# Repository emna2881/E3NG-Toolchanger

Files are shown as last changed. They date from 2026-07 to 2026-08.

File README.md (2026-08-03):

# E3NG-Toolchanger
A hotend-swapping toolchanger system modified for the E3NG (Ender-3 NG) 3D printer.

Render

> [!IMPORTANT]
> **Note: This project is currently in Beta. Community testing and feedback are greatly needed.**
> 
> **Some features(BOM, printer.cfg, marcos...) will be updated in a future release.**
## Credits
This project is based on E3NG by RH3D : https://github.com/RH3D/E3NG

Also, I designed mount for Metal Bed of Nudge probe for tool offset calibration. Thanks to zruncho3d for developing Nudge : https://github.com/zruncho3d/nudge

(+) The extruder design for this toolchanger was inspired by Irbis3D's MedusaHC (https://github.com/Irbis3D/MedusaHC). His DuEnder project and its accompanying hotend changer system, MedusaHC, are incredibly sophisticated and highly refined, and they were immensely helpful to me while designing the toolchanger system for the E3NG.

I would like to express my deepest gratitude to Irbis3D for his continuous efforts in advancing the Ender-3. Additionally, I sincerely apologize for the delay in adding this credit.

## Key Features
asdf

* Hotend-Swapping Mechanism: Swaps hotends while utilizing a single extruder drive gear set and a single pair of part cooling fans, significantly reducing toolhead weight and cost.
* Servo-Driven Cam Arm: Features a servo motor with a cam mechanism that disengages the extruder idler arm to clear the filament path for tool changes.
* Multi-Tool Capacity: Supports up to 6 tools (5 tools recommended for optimal clearance)

## Print Settings and Recommendations

To ensure mechanical strength and thermal resistance, please follow these guidelines when printing the parts:

### Material Selection
* Recommended: ABS or ASA (Best for enclosure heat resistance and structural integrity).
* Acceptable: PETG can be used if you are operating the printer without an enclosure.
* DO NOT USE PLA: PLA is strongly discouraged, especially for the hotend, toolhead, and carriage parts, due to heat deflection issues.

### Print Specifications
* Walls and Infill: Follow the official E3NG recommended print guidelines (e.g., 4 perimeters, 5 top/bottom layers, 30% infill)
* Supports: Most STL files are designed to be printed supportless. However, a few specific components require custom support setups (Detailed support guide will be added in a future update).

## License
This project is licensed under the terms of the [Creative Commons Attribution-NonCommercial-ShareAlike 4.0 International License](https://creativecommons.org/licenses/by-nc-sa/4.0/)


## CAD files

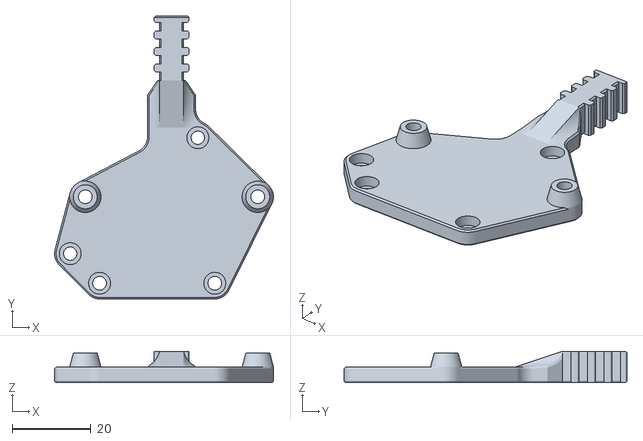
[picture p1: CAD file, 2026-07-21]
STLs/Accessories/E3NG_ToolChanger_ebb36_mount.stl
55.7 x 71.9 x 8.00

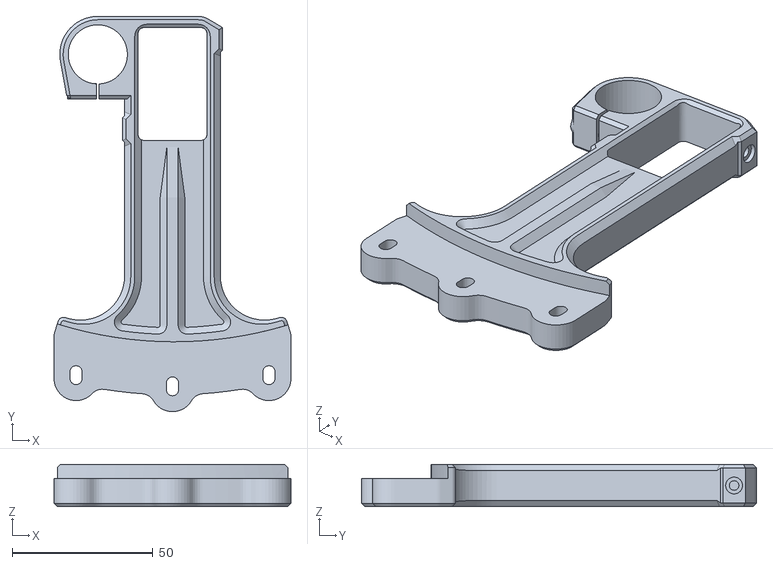
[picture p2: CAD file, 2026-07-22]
STLs/Bedcarriage/E3NG_ToolChanger_bed_arm_rear_flexi_tripple.stl
84.1 x 140.3 x 15.0

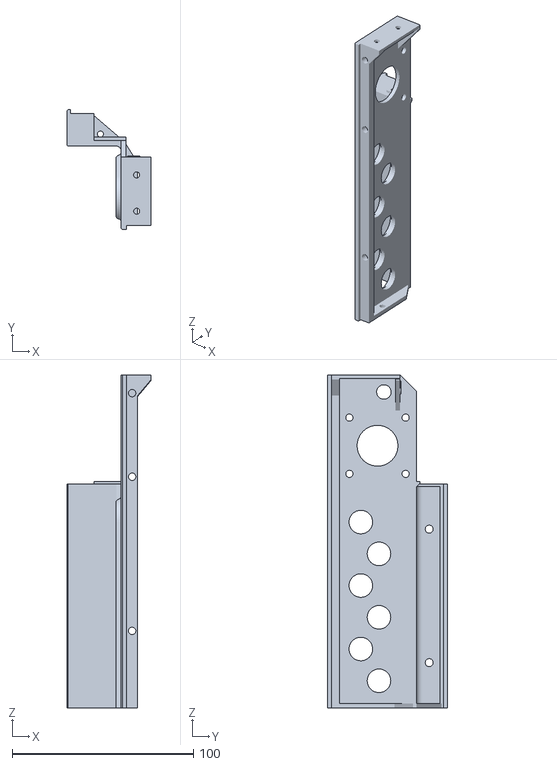
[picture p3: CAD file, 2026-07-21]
STLs/Electronics/E3NG_ToolChanger_electronics_top_A.stl
46.5 x 66.0 x 183.6

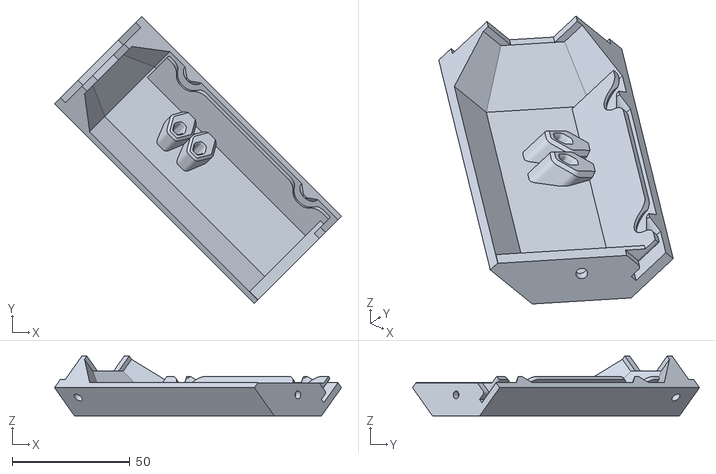
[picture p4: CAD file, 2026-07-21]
STLs/Enclosure/E3NG_ToolChanger_enclosure_lid_corner_left_2holes.stl
121.9 x 121.9 x 25.5

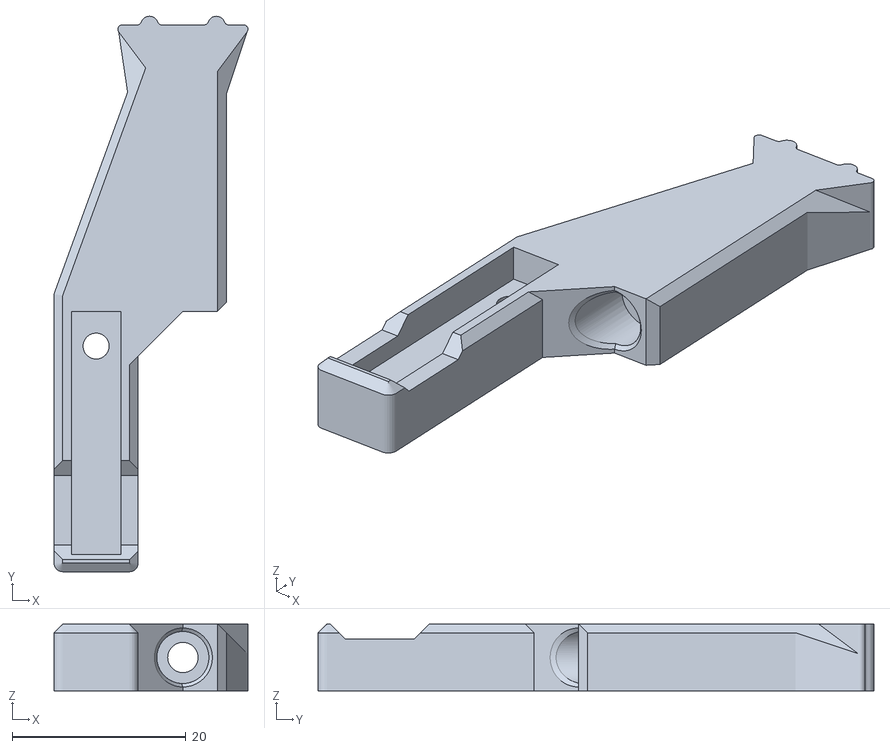
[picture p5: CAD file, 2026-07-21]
STLs/Experimental/E3NG_ToolChanger_nozzlewiper_wiper.stl
22.3 x 64.0 x 7.70

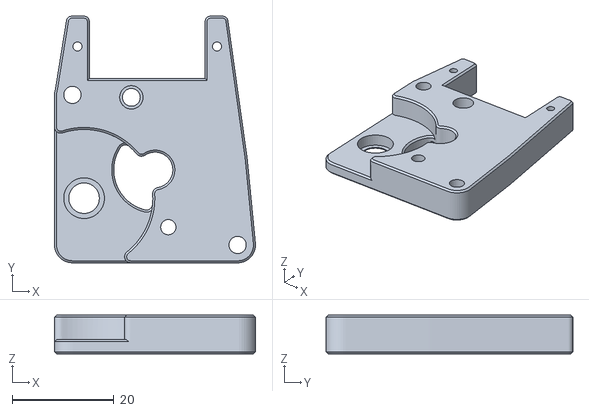
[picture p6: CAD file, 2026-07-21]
STLs/Extruder/E3NG_ToolChanger_extruder_base_with_pin.stl
39.5 x 48.5 x 7.60

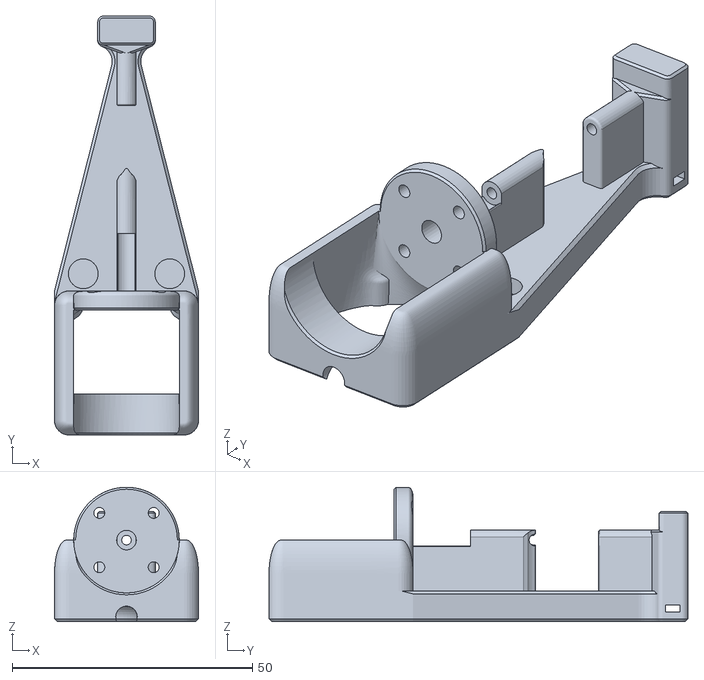
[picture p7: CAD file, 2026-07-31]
STLs/Tool/E3NG_ToolChanger_tool_A.stl
30.0 x 87.3 x 28.0

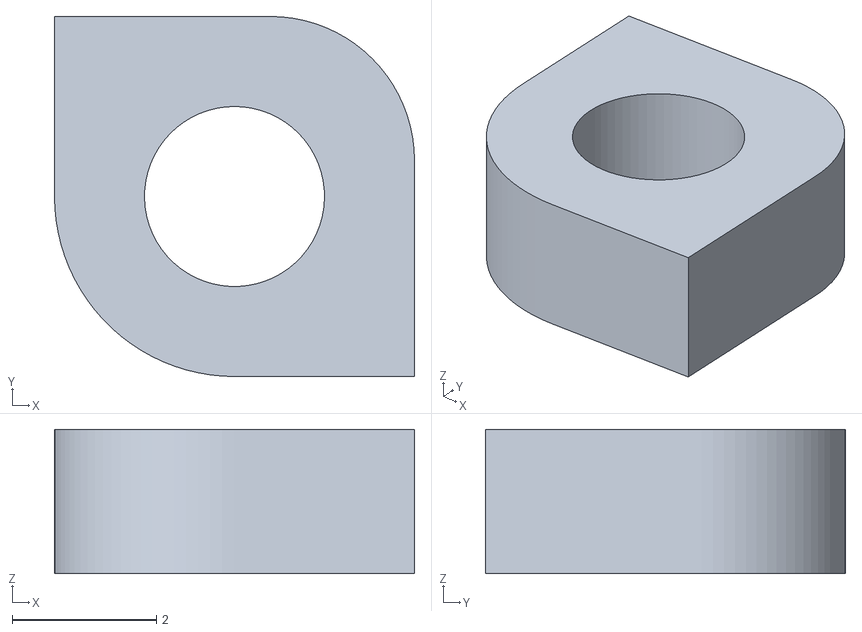
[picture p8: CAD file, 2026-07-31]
STLs/Toolhead/E3NG_ToolChanger_Fanduct_fan_spacer_2mm.stl
5.00 x 5.00 x 2.00

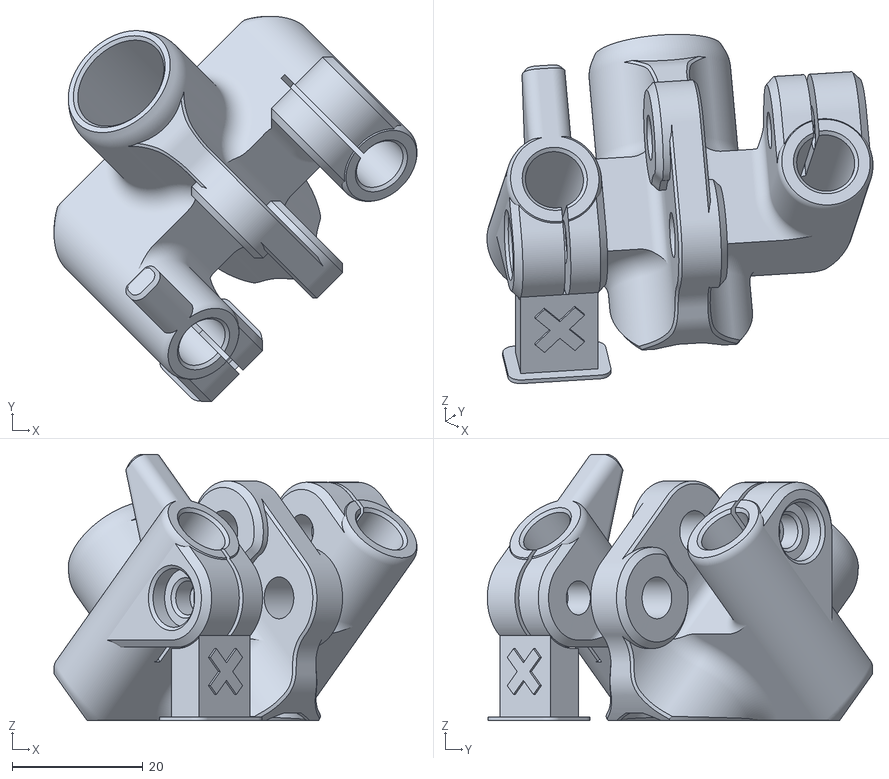
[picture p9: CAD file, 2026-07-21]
STLs/YGantry/E3NG_ToolChanger_y_gantry_v1.2_left.stl
55.5 x 59.0 x 40.8

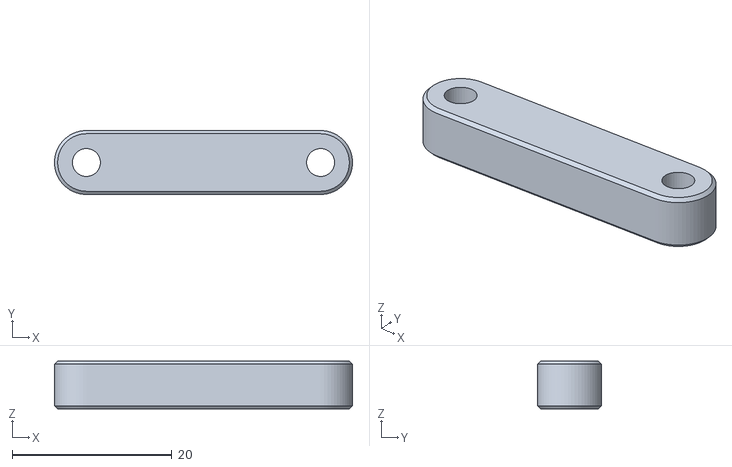
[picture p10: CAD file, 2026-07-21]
STLs/Accessories/E3NG_ToolChanger_ebbmount_spacer_6mm.stl
37.3 x 8.00 x 6.00

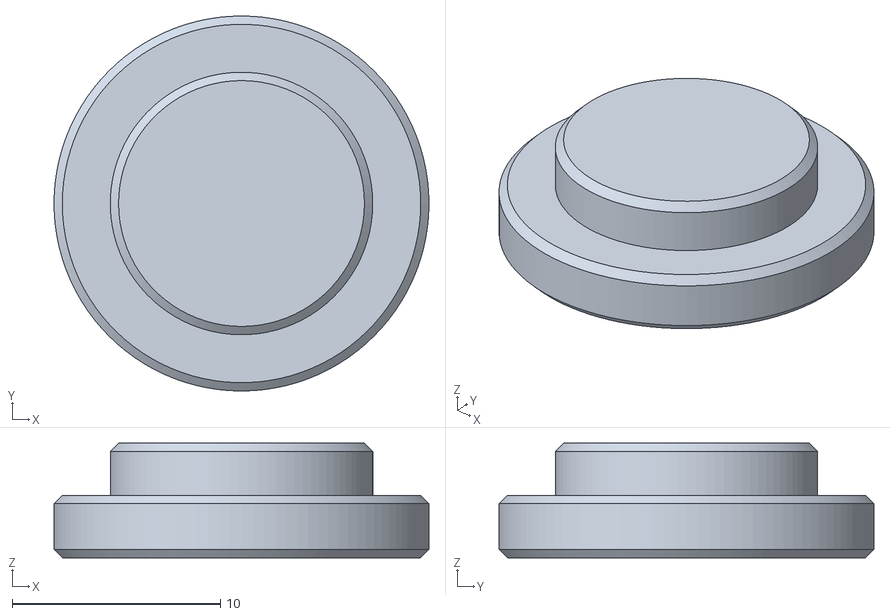
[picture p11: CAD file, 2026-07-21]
STLs/Electronics/E3NG_ToolChanger_electronics_top_A_hole_cover.stl
18.0 x 18.0 x 5.50

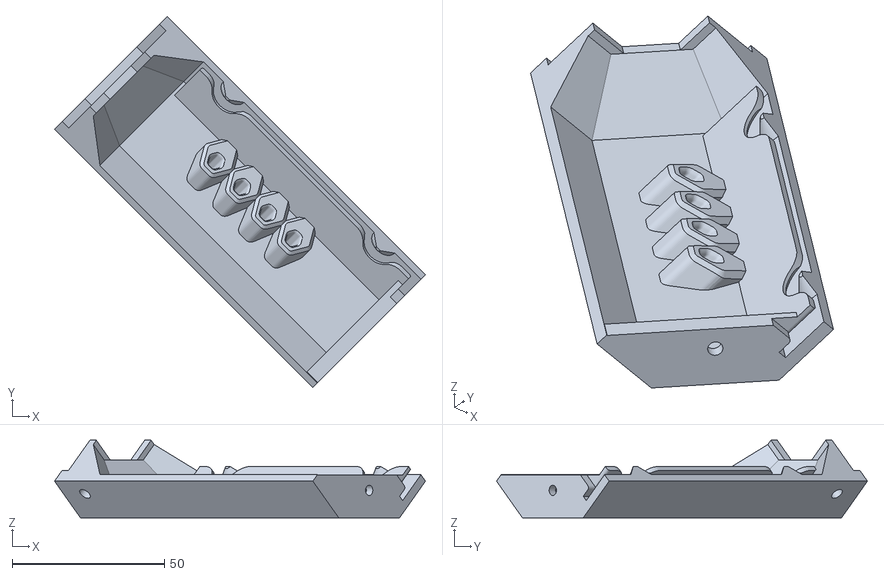
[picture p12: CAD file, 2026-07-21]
STLs/Enclosure/E3NG_ToolChanger_enclosure_lid_corner_left_4holes.stl
121.9 x 121.9 x 25.5

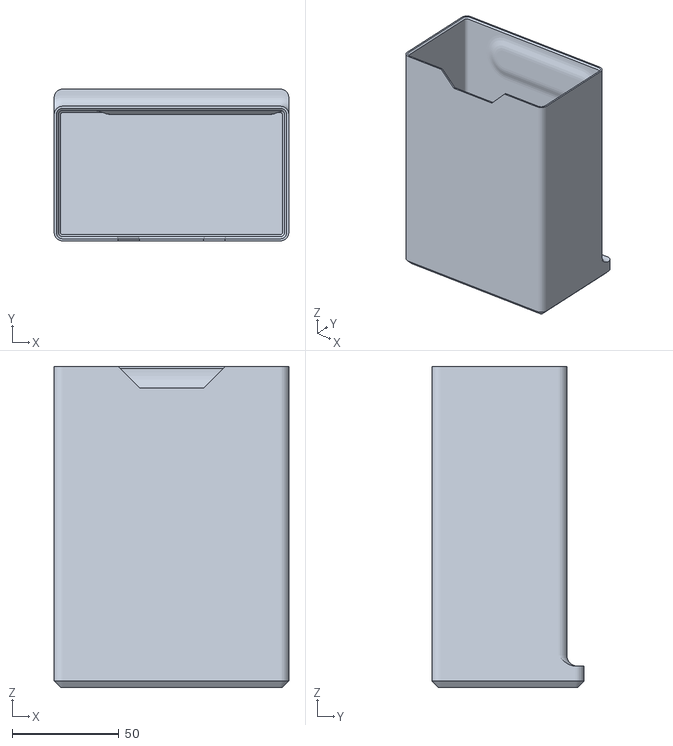
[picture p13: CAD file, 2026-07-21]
STLs/Experimental/E3NG_ToolChanger_nozzlewiper_bucket.stl
109.7 x 71.0 x 150.0

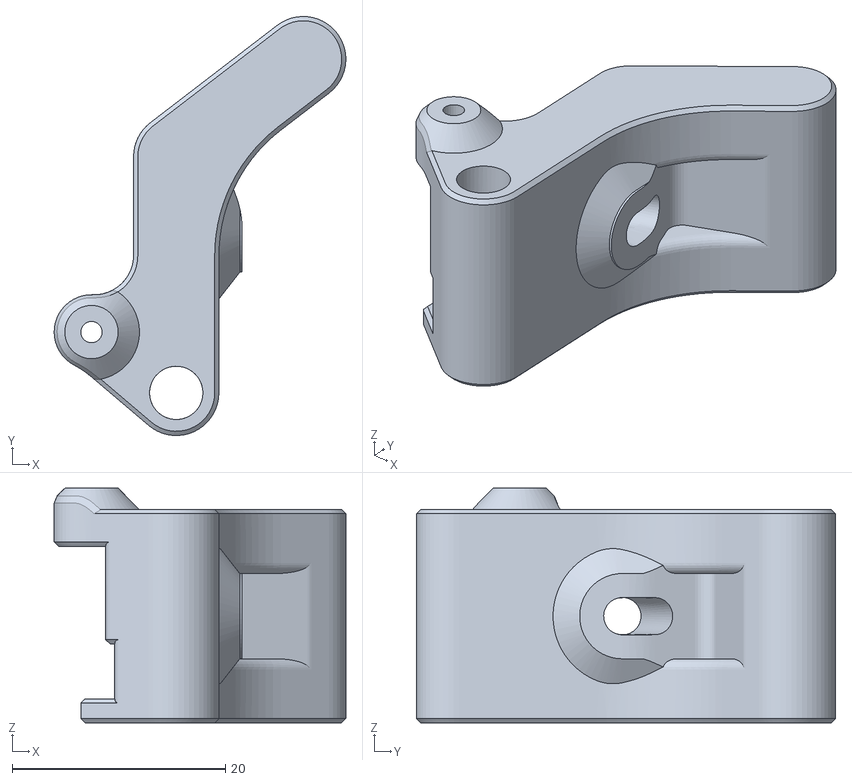
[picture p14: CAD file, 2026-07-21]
STLs/Extruder/E3NG_ToolChanger_extruder_arm_with_sleeve.stl
27.3 x 39.3 x 22.0

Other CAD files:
STLs/Tool/E3NG_ToolChanger_dock_B.stl
STLs/Toolhead/E3NG_ToolChanger_Toolhead_base.stl
STLs/YGantry/E3NG_ToolChanger_y_gantry_beta_B.stl
STLs/Accessories/E3NG_ToolChanger_ebbmount_spacer_3.5mm.stl
CAD/E3NG_Toolchanger_Profile_Bracket.f3d
STLs/Accessories/E3NG_ToolChanger_ebb42_mount.stl
STLs/Enclosure/E3NG_ToolChanger_enclosure_lid_corner_right_2holes.stl
STLs/Enclosure/E3NG_ToolChanger_enclosure_lid_corner_right_4holes.stl
STLs/Experimental/E3NG_ToolChanger_nozzlewiper_base.stl
STLs/Experimental/E3NG_ToolChanger_nudge_base_for_metal_bed.stl
STLs/Experimental/E3NG_ToolChanger_tool_park_left.stl
STLs/Experimental/E3NG_ToolChanger_tool_park_right.stl
STLs/Extruder/E3NG_ToolChanger_extruder_arm.stl
STLs/Extruder/E3NG_ToolChanger_extruder_base.stl
STLs/Extruder/E3NG_ToolChanger_extruder_core.stl
STLs/Extruder/E3NG_ToolChanger_extruder_core_with_pin.stl
STLs/Tool/E3NG_ToolChanger_dock_A.stl
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

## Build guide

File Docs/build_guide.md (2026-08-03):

# E3NG Toolchanger Official Documentation & BOM Guide

> *Disclaimer: This document was created with the assistance of AI translation. Please note that there may be awkward phrasing or grammatical errors, and we ask for your understanding.*

## General Build Guidelines
- **Bolt Substitution:** All 14mm bolts listed in the guide can be replaced with 15mm bolts.
- **Magnet Insertion:** When inserting magnets, using CA glue (superglue) is recommended to ensure they are firmly and permanently secured.

---

## Detailed Component Guide & BOM
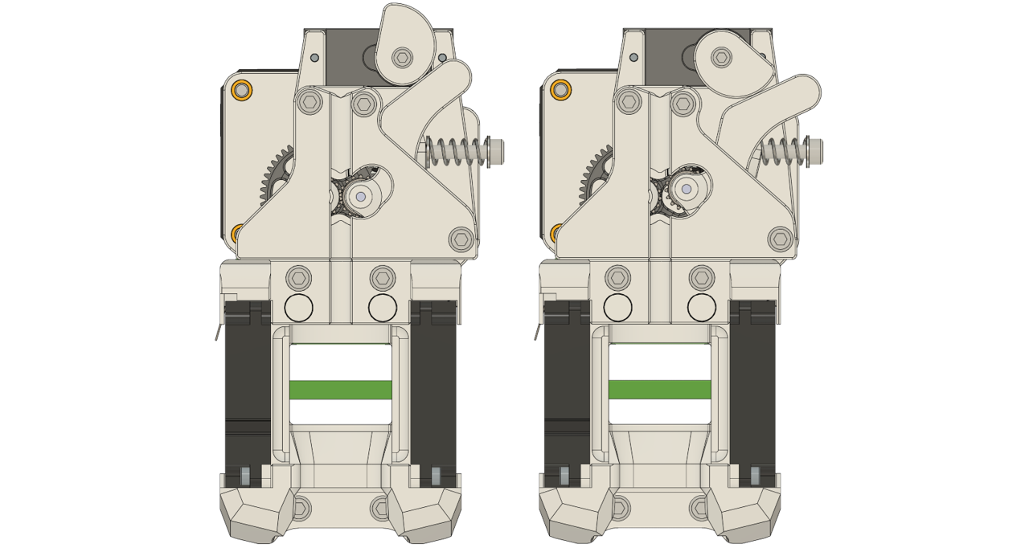
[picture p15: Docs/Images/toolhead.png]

The toolhead structure is simple and intuitive. A cam attached to the servo motor rotates to open the extruder gears. The tool and toolhead are securely held together by two pairs of neodymium magnets.

### 1. Extruder
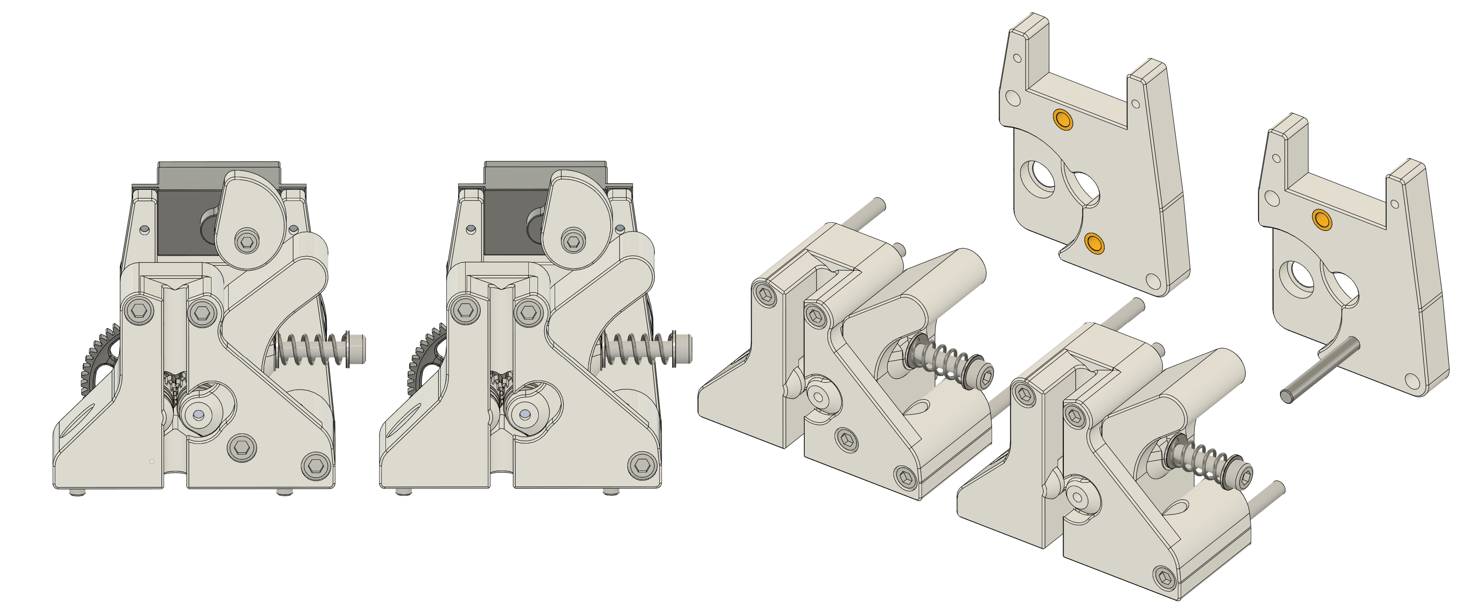
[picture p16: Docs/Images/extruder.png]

Two versions of the extruder are available:
1. **Use the Pin (Recommended):** Use the unthreaded 3x30mm pin included in the BMG gear kit.
2. **Use the M3x25mm Bolt:** Use an M3 SHCS 25mm instead of the pin.

I recommend using the unthreaded pin. However, if you are using that specific pin for a Nudge probe, you can substitute it with the M3 SHCS model.

> **[CRITICAL]** **DO NOT** use the **stock spring** included in the **BMG extruder gear kit** for this toolchanger build. It is **far too strong** and will **not work properly** in this application. You must **replace it** with a **compression spring** of the **correct spring rate**. I used a **SUS304** compression spring with the following specifications: **wire diameter 0.7mm**, **outer diameter 6mm**, and **length 15mm**.

*(Note: A version requiring a sleeve (OD 5mm, ID 3mm, Length 20mm) for the extruder lever is available but not strictly necessary to use.)*

**[BOM]**
- 1x BMG Extruder Kit (must be compatible with the Sherpa Mini or Sherpa Micro)
- 1x NEMA14 10T Stepper Motor
- 1x SG90s Servo Motor
- 2x M3 SHCS 35mm
- 1x M3 SHCS 30mm
- 3x M3 SHCS 25mm
- 2x M3 SHCS 8mm
- 2x M3 Washers
- 3x M3 Heat Set Inserts (OD 4.5mm, L 4mm)
- 1x M2.5 SHCS 6mm
- 2x M2 SHCS 8mm

### 2. Fan Duct
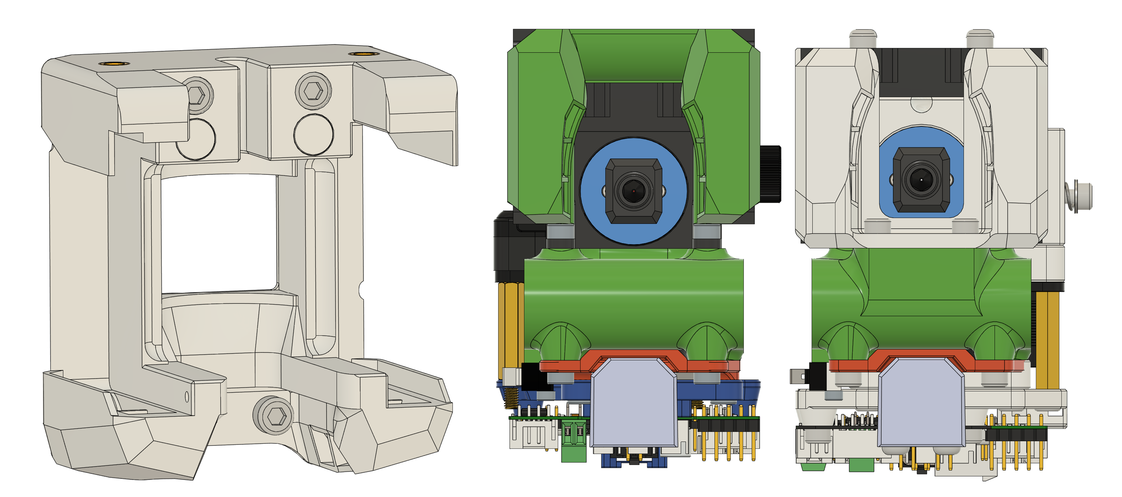
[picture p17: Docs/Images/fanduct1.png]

The fan duct model retains the original E3NG 4010 fan duct shape, aligned perfectly with the nozzle position.
Each blower fan must be secured with two bolts. Depending on the brand of blower fan you use, there might be a small gap at the mounting holes. We recommend printing a spacer(/STLs/Toolhead/E3NG_ToolChanger_Fanduct_fan_spacer_2mm.stl) to fill this gap. (The default model is optimized for GDSTime fans. For other brands, measure the gap manually and adjust the spacer thickness accordingly.)
Route the wiring for the left blower fan through the upper clearance space for neat cable management.
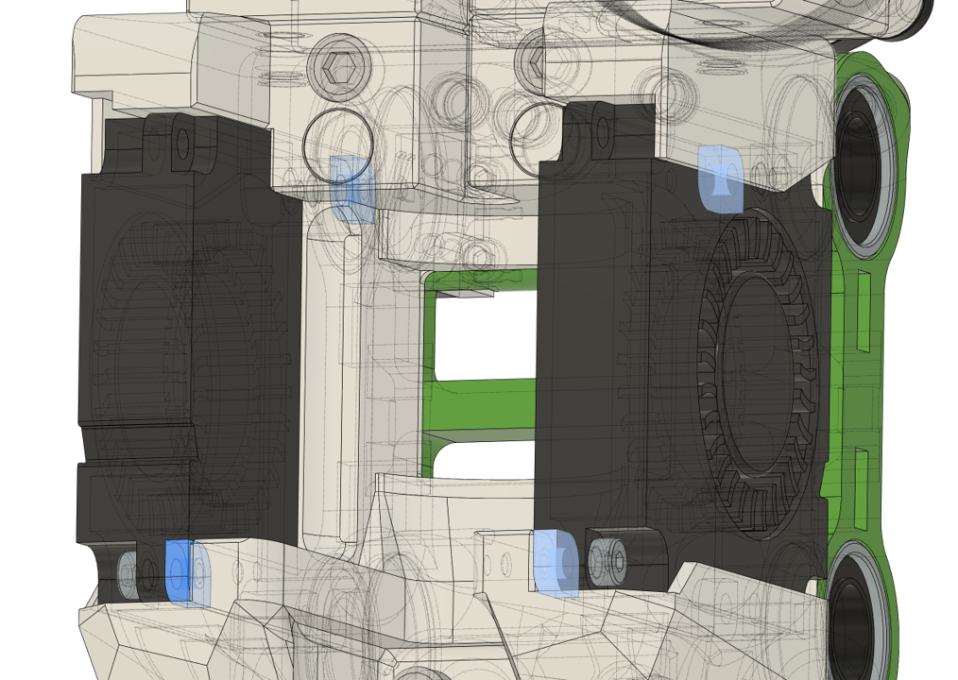
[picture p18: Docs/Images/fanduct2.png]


**[BOM]**
- 2x 4010 Blower Fans
- 2x Neodymium Magnets (OD 6mm, H 3mm)
- 2x M3 SHCS 25mm
- 2x M3 SHCS 6mm
- 2x M3 Heat Set Inserts (OD 4.5mm, L 4mm)
- 4x M2 SHCS 8mm

### 3. Toolboard
Mounts for both the **EBB36** and **EBB42** are available.
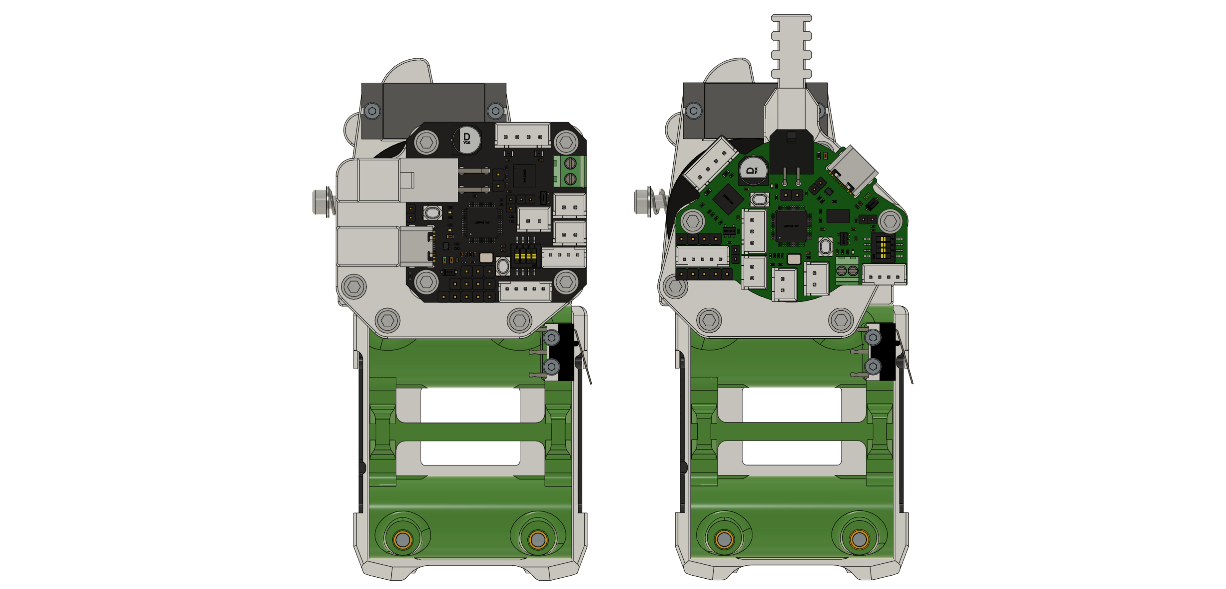
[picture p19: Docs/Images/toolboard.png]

The EBB36 version routes cables upwards, which may cause annoying interference with the hotend wiring. Therefore, I highly recommend using the EBB42, which neatly routes cables to the side.
*(Note: The EBB42 mount requires an additional 2x M3 heat set inserts and 2x M3 SHCS 8mm.)*

*Caution: The design was not modeled with **Gen2** compatibility in mind, so proceed with caution.*

*You can reuse your existing probe without issues.*

**[BOM]**
- 1x EBB42 or EBB36
- 2x M3 Standoffs (20mm)
- 6x M3 SHCS 8mm (+2 extra if using EBB42)
- 2x M3 SHCS 12mm
- 4x M3 Heat Set Inserts (OD 4.5mm, L 4mm) (+2 extra if using EBB42)

### 4. X Gantry
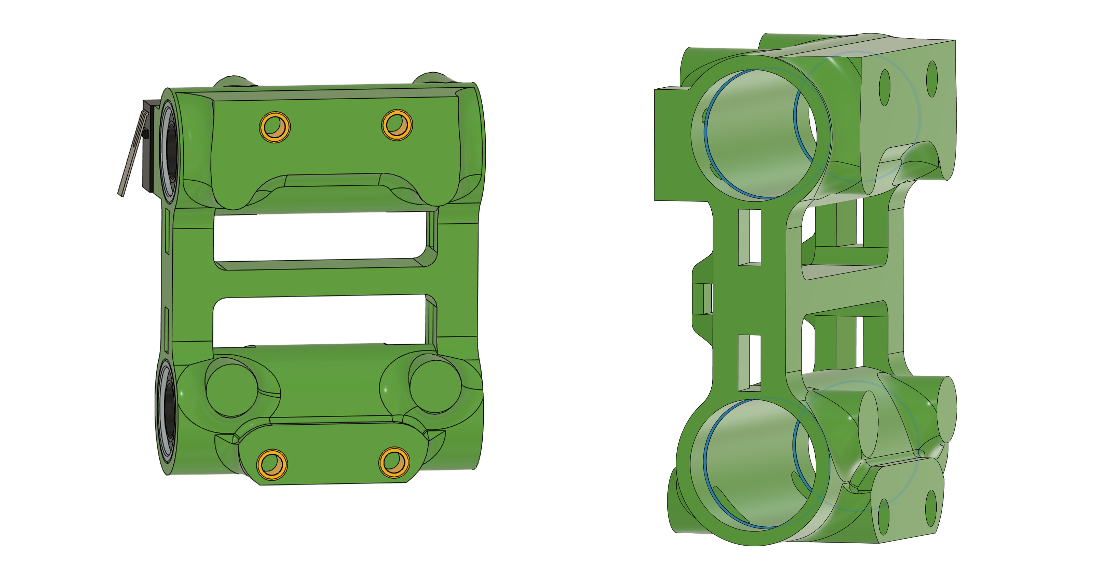
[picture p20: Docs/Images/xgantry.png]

The X Gantry shape has been modified to accommodate the toolchanger fan duct and must be reprinted.
A reinforcement bar has been added to the center, along with protrusions inside the linear bushing holes to secure the bushings better. If the tolerance on these holes is too loose, the linear bushings will wobble. Ensure your slicer settings provide tight tolerances for this part.

**[BOM]**
- 2x LM8LUU Linear Bearings
- 1x D2F-L Limit Switch
- 8x M3 Heat Set Inserts (OD 4.5mm, L 4mm)
- 2x M2 SHCS 10mm

### 5. Y Gantry
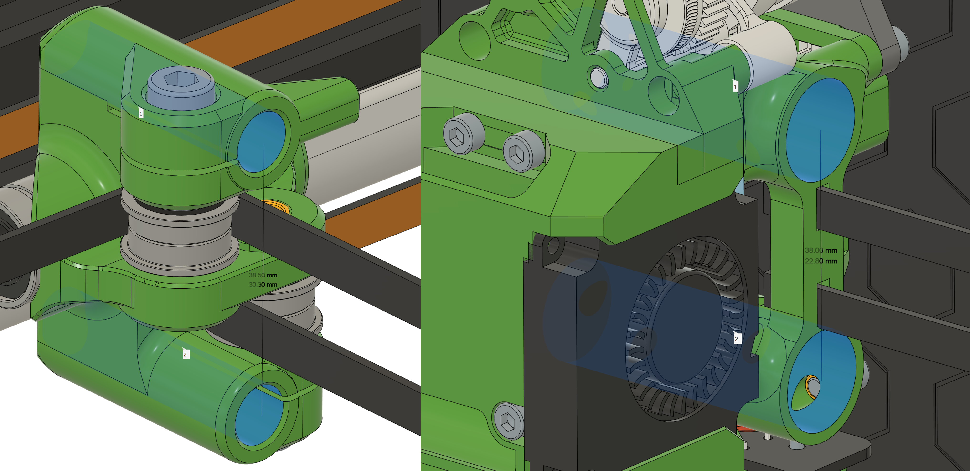
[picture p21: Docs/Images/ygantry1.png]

A discrepancy was discovered in previous models: the distance between smooth rods on the original Y-block was 38.5mm, while the distance between linear bushings on the X-gantry was 38mm.

I corrected and standardized the spacing to 38mm, and realigned the bearings and belts. If your current setup works fine, you don't have to rebuild it. But if you are building a new one or replacing the Y-blocks, use this updated version.

Additionally, a Beta-style Y-block has been included. If you are currently using the E3NG Beta Y-blocks for V1.2, you MUST upgrade to this new Beta style. The old beta blocks will collide with the fan duct, restricting your X-axis movement. 
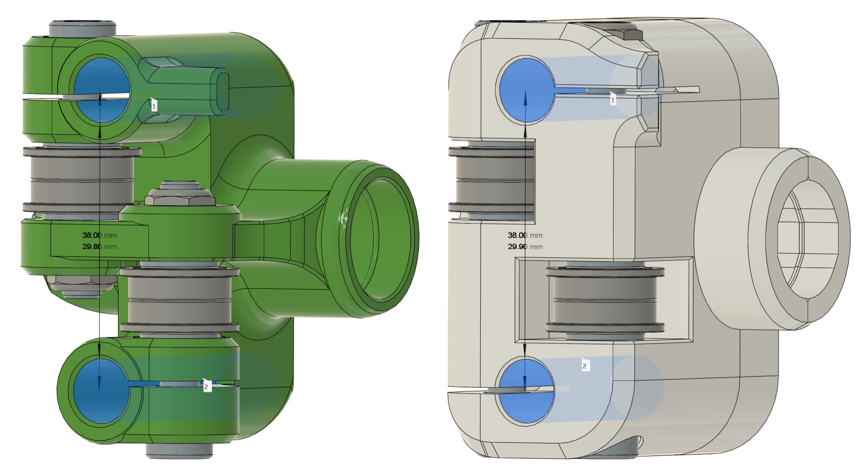
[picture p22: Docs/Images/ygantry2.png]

The fastening method for all Y-blocks has been changed from heat-set inserts to nylon lock nuts. Inserts sometimes caused twisting and part breakage during tightening; nylon nuts provide a secure, anti-vibration lock without over-tightening. Like the X Gantry, protrusions have been added to the linear bushing holes to clamp them securely.

Assembly Notes:
- V1.2 Style: Insert the linear bushings flush with the end of the printed part.
- Beta Style: Align the groove of the linear bushing with the protrusion on one half of the printed part, then bolt the two halves together. Verify that the bearings are firmly clamped after assembly.


**[BOM]**
- 2x LM8LUU Linear Bearings
- 4x M5 Nylon Nuts
- 8x M5 Washers
- 8x F695 Bearings

For V1.2 Style Y-blocks:
- 4x M5 SHCS 30mm

For Beta Style Y-blocks:
- 4x M5 SHCS 50mm
- 8x M3 SHCS 15mm
- 8x M3 Heat Set Inserts (OD 4.5mm, L 4mm)

### 6. Hotend (Tool)
[ATTENTION] The BOM below is per ONE tool. Multiply the quantities by the total number of tools you plan to build.

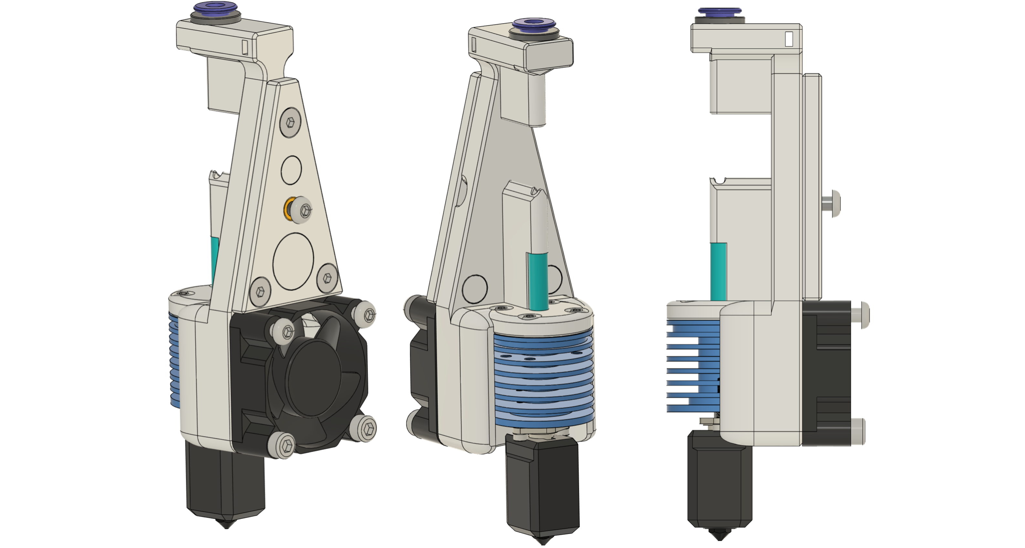
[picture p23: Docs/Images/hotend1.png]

We use the TZ-V6 3.0 hotend. Before installing the hotend, cut the PTFE tube to an exact length of 18mm and insert it.
Remove the default V6 mount attached to the TZ-V6 3.0, and secure it using four M2.5 BHCS 6mm. *(Note: The M2.5 BHCS 8mm included in the hotend kit may touch the heatsink. It is usable, but we strongly recommend sourcing M2.5 BHCS 6mm instead.)*
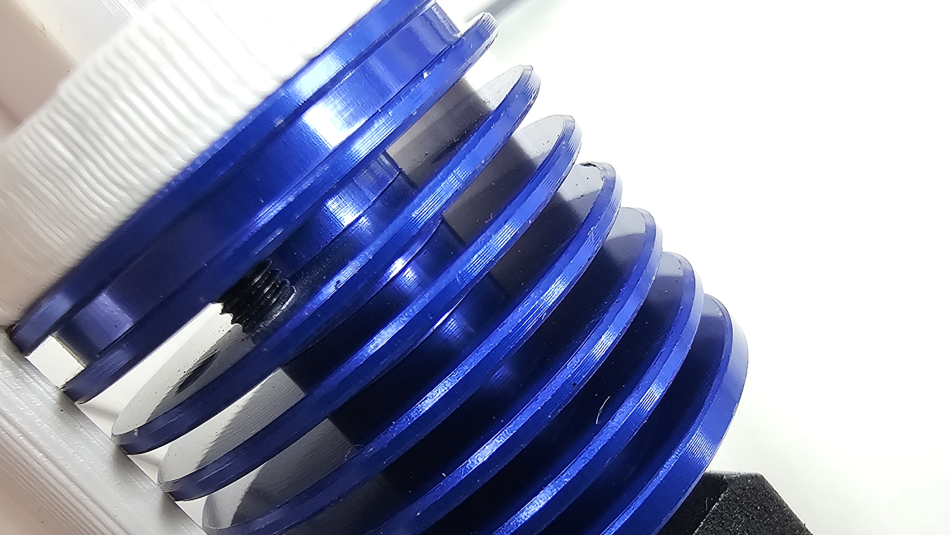
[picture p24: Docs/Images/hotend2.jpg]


For the ECAS04 fitting, remove the bottom rubber component and use only the top plastic section. Double-check the magnetic polarity before inserting any magnets. 
At the front of the tool, three BHCS are used for docking/parking the tool. You can substitute these with SHCS, but DO NOT use FHCS. These three bolts should not be tightened all the way; the bolt heads must protrude by at least 2mm. We advise applying CA glue to lock them permanently.
Please note that this section requires four 3mm height heat set inserts (not the standard 4mm), so be cautious during insertion.
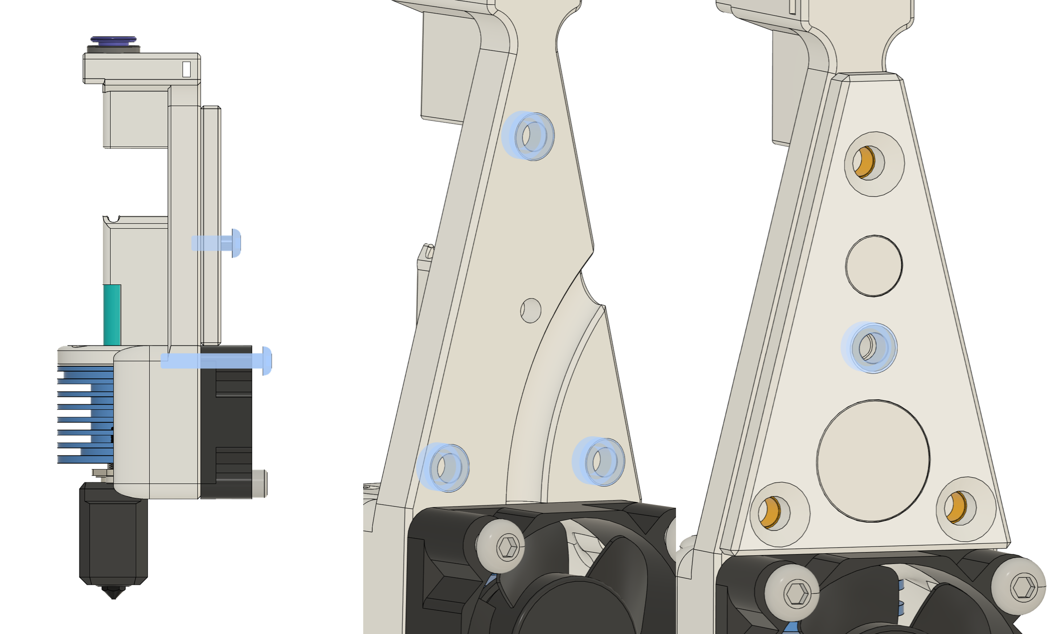
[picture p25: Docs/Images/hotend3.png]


[BOM - Per Tool]
- 1x TZ-V6 3.0 Hotend
- 1x 3010 Fan
- 1x PTFE TUBE (ID 2mm/1.9mm, OD 4mm, Length: 18mm)
- 1x ECAS04 Fitting (top part only)
- 3x Neodymium Magnets (OD 6mm, H 3mm)
- 1x Neodymium Magnet (OD 12mm, H 3mm)
- 2x M3 SHCS 14mm
- 2x M3 BHCS 20mm
- 1x M3 BHCS 8mm
- 3x M3 FHCS 6mm
- 4x M3 Heat Set Inserts (OD 4.5mm, L 4mm)
- 4x M3 Heat Set Inserts (OD 5.0mm, L 3mm)
- 4x M2.5 BHCS 6mm (Recommended)

### 7. Tool Dock

The default models are designed for a 330mm extrusion profile, but the system supports profiles up to 350mm. To adjust for a different profile length:

1. Open Autodesk Fusion and load E3NG_Toolchanger_Profile_Bracket.f3d from the CAD folder.
2. Modify the dimension parameter to match your extrusion length. The model geometry will automatically update.
3. Export the updated body as a mesh and slice/print.
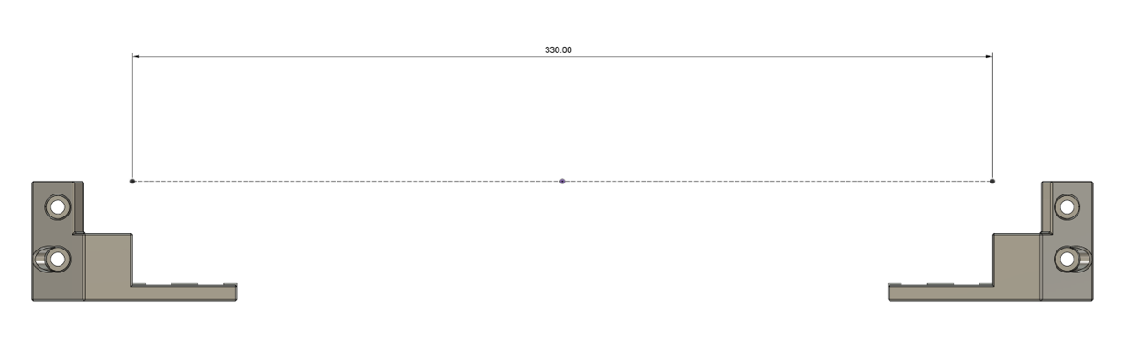
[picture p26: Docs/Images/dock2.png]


[CRITICAL] When assembled with the profile, the total distance from end to end of the dock MUST be exactly 407mm. Even a 0.5mm deviation will cause severe gantry twisting, so ensure this measurement is precise. 
The brackets are designed for Ender-3 style V-slot extrusions. If you are using European standard extrusions (e.g., Misumi), you will need to modify the models.

[BOM - Profile Bracket]
- 4x M5 SHCS 8mm
- 2x M5 SHCS 15mm
- 4x M5 T-Nuts

[BOM - Per Tool Docking Slot]
- 1x Neodymium Magnet (OD 12mm, H 3mm)
- 1x Neodymium Magnet (OD 6mm, H 3mm)
- 2x M4 SHCS 20mm
- 2x M4 FHCS 10mm
- 4x M4 T-Nuts

### 8. Electronics - Top
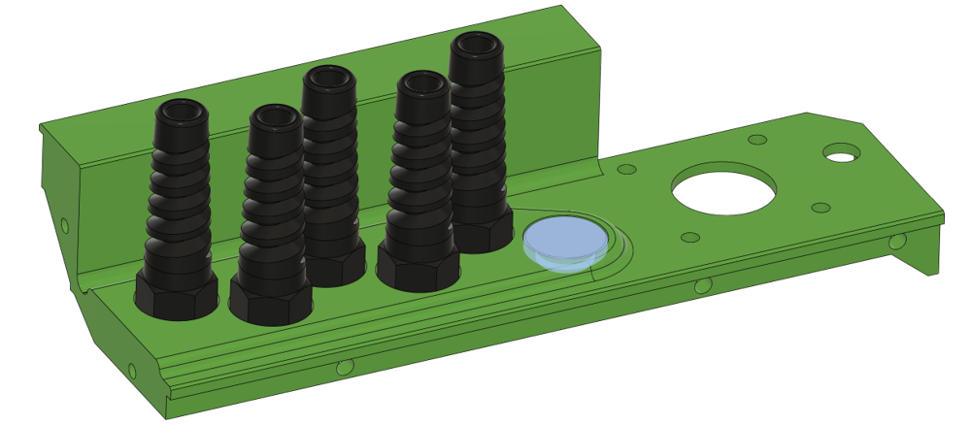
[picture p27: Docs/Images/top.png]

Additional holes have been added to smoothly route the hotend wiring. Use a PG7 flexible cable gland, or use the provided printable alternative instead. Plug any unused holes by printing the hole_cover model.

**[BOM]**
- PG7 Flexible Cable Gland (or printed alternative)

### 9. Enclosure
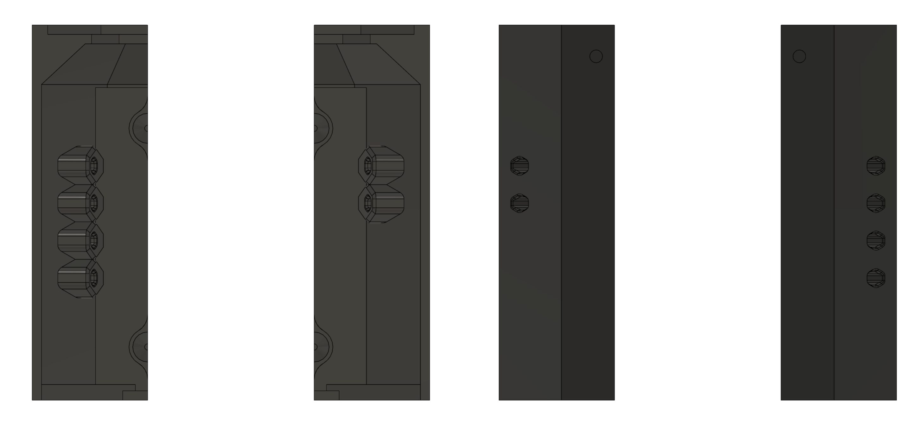
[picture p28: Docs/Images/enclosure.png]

I have added lid corner models with 4 and 2 holes to route multiple PTFE tubes out of the enclosure. The current design assumes an external setup with 4 spools on the left and 2 on the right. 
Options for a 3/3 split or an internal spool holder are currently under consideration for future updates.

---

## Experimental Features
Models located in the /Experimental folder are highly experimental and may not work perfectly depending on your setup. Use them at your own risk.

### Nozzle Wiper
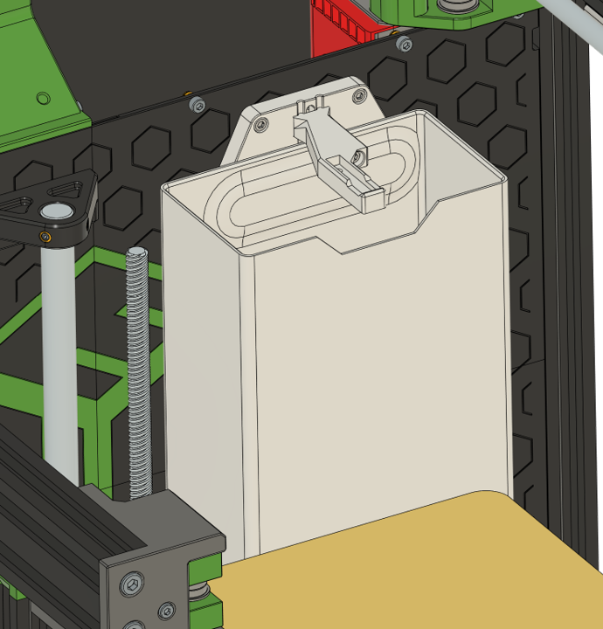
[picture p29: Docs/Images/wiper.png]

To maintain print quality during tool changes, we highly recommend a slight purge and wipe sequence for every nozzle swap. Because toolchangers require minimal purging, the bucket size may be reduced in future iterations. Use a Bambu Lab A1 mini silicone brush for the wiper.

Note: If you are using the stock or printed bed carriage, the bucket will collide with the Nudge (or Sexbolt). In this case, print and use the provided alternative bed arm, which flips the position of the insert used to mount the sexbolt.
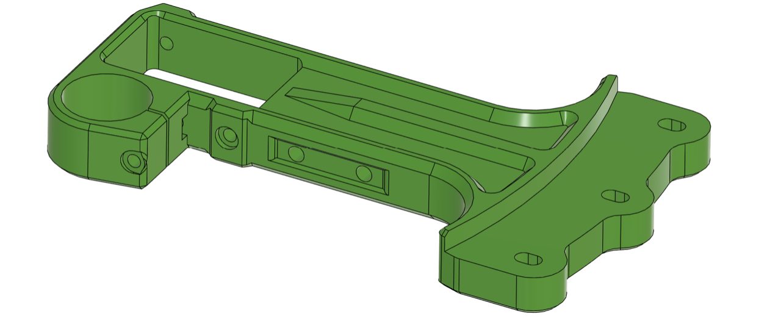
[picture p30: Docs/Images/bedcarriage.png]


**[BOM]**
- 4x Neodymium Magnets (OD 12mm, H 3mm)
- 1x Silicone Nozzle Brush for Bambu Lab A1 Mini
- 1x M3 SHCS 35mm
- 3x M3 SHCS 10mm
- 1x M3 Nut

### Nudge Base for Metal Bed
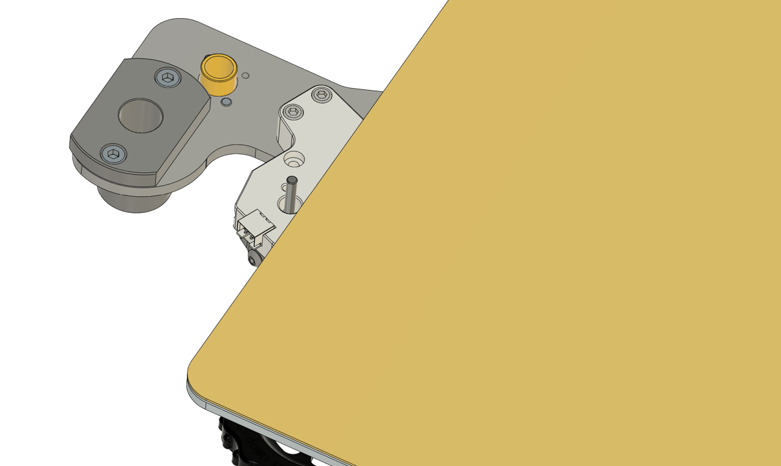
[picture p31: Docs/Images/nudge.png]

A dedicated Nudge base intended for use with metal bed carriages. Keep the original Nudge Wobbler part and only reprint and replace the base component.

**[BOM]**
- 4x M3 SHCS 12mm
- (Remaining original Nudge components)

### Tool Park

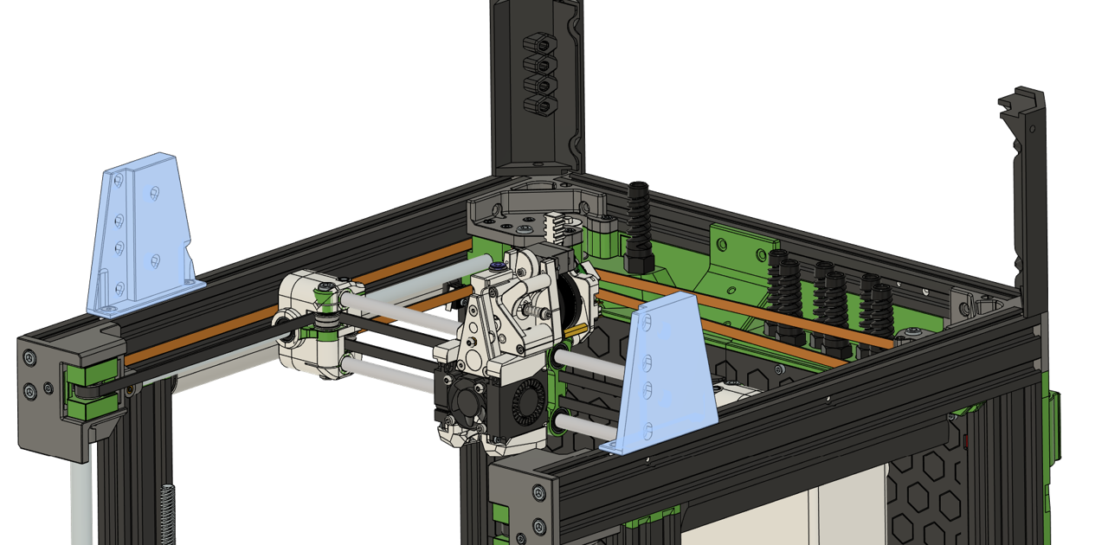
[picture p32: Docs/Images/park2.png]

Implementing a toolchanger natively results in a loss of about 50mm in the Y-axis build volume. When printing in a single color (single tool), you can "park" unused tools on this structure to reclaim that lost volume. Essentially, this allows you to utilize the full 230x230mm build volume exclusively for single-filament prints.
However, this structure only holds up to 4 tools, making it unsuitable if you are running a full 6-tool system.

**[BOM]**
- 4x M4 FHCS 8mm
- 4x M4 T-Nuts

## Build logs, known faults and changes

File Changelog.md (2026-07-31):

# Changelog

## Jul 31, 2026
* **Redesigned the Tool and Fan Duct**
  
  
  The design of the hotend assembly (Tool) and its supporting fan duct has been updated. 
  
  **Tool Update:** The overall size of the printed tool part has been reduced while providing a much firmer and more secure grip on the hotend than before.
  
  **Fan Duct Update:** The revised fan duct design also holds the hotend better than the previous shape. Additionally, the structural rigidity of the printed part has significantly increased, resolving the issue of it bending easily like the older design.

## Jul 21, 2026
* Initial Release

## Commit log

2026-07-21 Add CAD and STL files
    [E3NG_ToolChanger_Toolhead_base.stl, E3NG_ToolChanger_dock_A.stl, E3NG_ToolChanger_dock_B.stl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]
2026-07-22 Add STLs/Bedcarriage/E3NG_ToolChanger_bed_arm_rear_flexi_tripple.stl, update STLs/Tool/E3NG_ToolChanger_dock_A.stl & E3NG_ToolChanger_dock_B.stl & E3NG_ToolChanger_tool_B.stl
    [E3NG_ToolChanger_bed_arm_rear_flexi_tripple.stl, E3NG_ToolChanger_dock_A.stl, E3NG_ToolChanger_dock_B.stl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]
2026-07-31 Update Tool and Fanduct Design(Adding Changelog.md)
    [E3NG_ToolChanger_tool_A.stl]
2026-07-31 Add /Docs/build_guide.md
    [E3NG_ToolChanger_Fanduct_fan_spacer_2mm.stl]
